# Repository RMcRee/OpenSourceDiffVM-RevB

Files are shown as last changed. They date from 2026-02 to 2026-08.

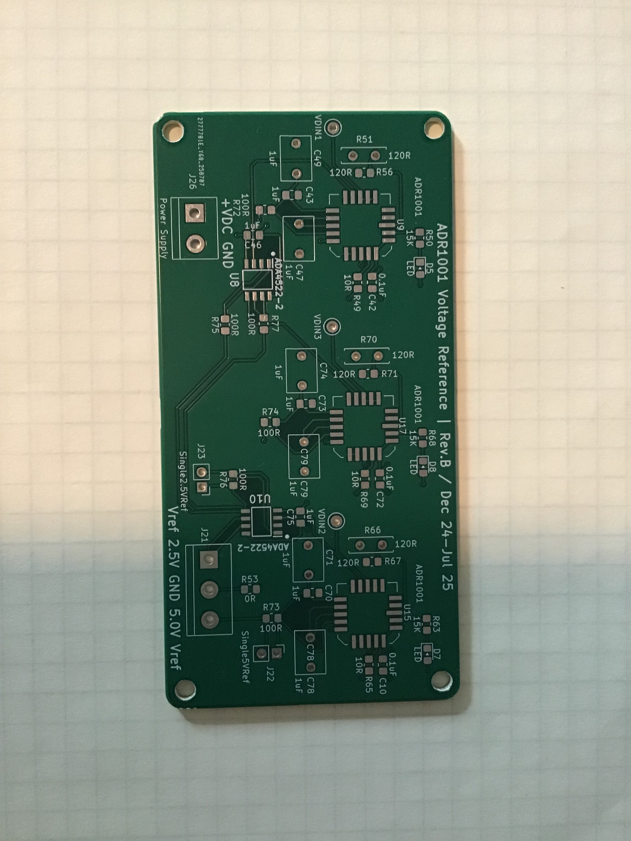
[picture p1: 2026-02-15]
ADR1001-board.jpg

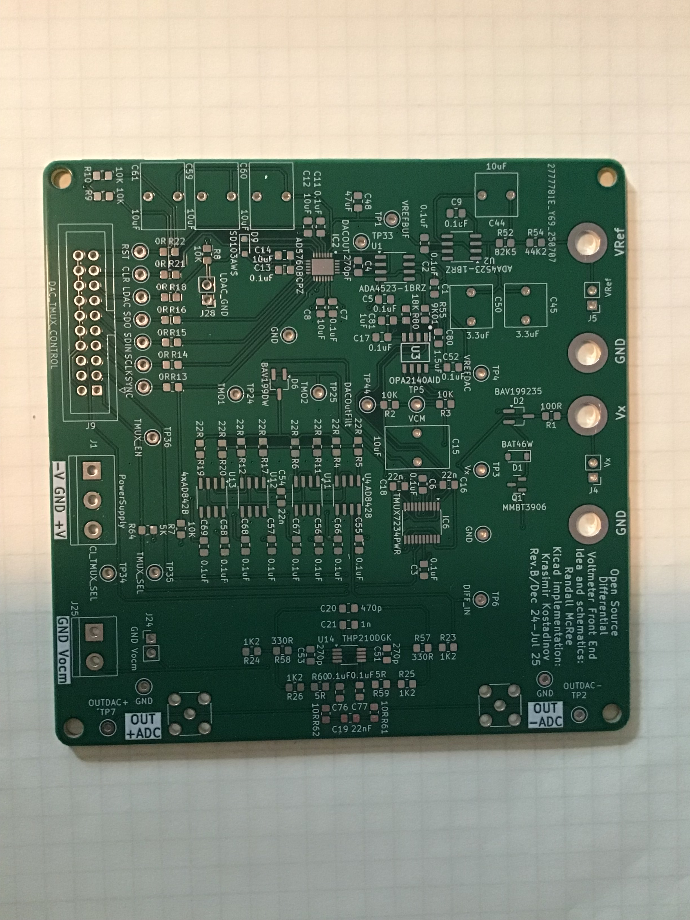
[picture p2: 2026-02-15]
Analog-front-end-board.jpg

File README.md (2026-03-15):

# Who is responsible
```
Schematic by Randall McRee 
PCB layout by Krasimir Kostadinov 
Software mostly from Claude 
```

# OpenSourceDiffVM-RevB

A high-resolution differential voltmeter (8.5-9.5 digit) with nanovolt-level sensitivity, based on the Analog Devices article on [low-noise instrumentation amplifiers](https://www.analog.com/en/resources/analog-dialogue/articles/low-noise-inamp-nanovolt-sensitivity.html).

## How It Works

An unknown voltage Vx is compared against a precision 16-bit DAC using a chopped measurement topology. The DAC output tracks Vx to within a few millivolts, and a high-gain instrumentation amplifier amplifies the residual difference for digitization by a 24-bit ADC. Chopping at ~385 Hz cancels preamp offset and 1/f noise.

```
Unknown Vx ──┐
             ├──[TMUX SPDT]──► AD8428 x4 ──► ADS127L11 ──► Teensy 4.x
DAC Output ──┘   (chopped)    (×2000 gain)   (24-bit ADC)
```

**Measurement equation:** `Vx = DAC_voltage + (ADC_mean / preamp_gain) × divider_ratio`

The DAC is calibrated against three ADR1001 ultra-stable voltage references (0.05 ppm/C) with 1000+ hour burn-in. Real-time drift compensation tracks the reference filter lag.

## Key Components

| Component | Function |
|---|---|
| 4x AD8428 | Ultra-low-noise instrumentation amplifier (1.5 nV/rtHz), gain = 2000 |
| TMUX7234 | Low-charge-injection SPDT switches for input chopping |
| ADS127L11 | 24-bit delta-sigma ADC, ~3906 SPS |
| AD5760 | 16-bit precision DAC, tracks unknown input |
| 3x ADR1001 | Ultra-stable voltage references, filtered and averaged |
| Teensy 4.1 | ARM Cortex-M7 @ 600 MHz, hardware 64-bit double |

## Voltage Ranges

| Range | Method | Resolution |
|---|---|---|
| +/-5V | Direct input | ~0.15 nV/count |
| +/-50V | Caddock 1776-C4815 divider (1:10, hardwired) | ~1.5 nV |
| +/-500V | Parallel tap (1:108.76) | ~16 nV |
| +/-5kV | Parallel tap (1:984.65) | ~150 nV |

## Firmware

The firmware runs on Teensy 4.1 and provides:

- **Serial command interface** over USB (115200 baud) — type `help` for commands
- **Channel scanning** — configure a scan list of up to 7 input channels
- **Three output modes** — human-readable, CSV for logging, Arduino Serial Plotter
- **Configurable integration** — 10 to 10,000 chop cycles per reading
- **Auto-zero** — periodic GND measurement for offset tracking
- **Reference drift compensation** — real-time prediction of filter lag error
- **DAC auto-adjustment** — binary search to keep preamp in range
- **Power-on self-test** — 9 hardware verification tests
- **EEPROM persistence** — save/load configuration across power cycles

### Building

Requires [Teensy board support](https://www.pjrc.com/teensy/td_download.html) for Arduino.

```bash
# Arduino CLI
arduino-cli compile --fqbn teensy:avr:teensy41 OpenSourceDiffVM-RevB.ino
arduino-cli upload --fqbn teensy:avr:teensy41 -p COM_PORT OpenSourceDiffVM-RevB.ino
```

### Serial Commands

Connect at 115200 baud. Key commands:

```
scan add Vx          # Add channel to scan list
scan add VrefRaw     # Add another channel
scan start           # Begin scanning
scan stop            # Stop scanning
log start            # Switch to CSV output
plot start           # Switch to Serial Plotter output
integrate 200        # Set 200 chop cycles per reading
autozero on          # Enable periodic zero calibration
range 100            # Set HV divider to +/-500V
zero                 # Immediate zero calibration
status               # Show current configuration
config save          # Persist to EEPROM
help                 # List all commands
```

### CSV Output Format

```
# timestamp_ms,channel,voltage_V,uncertainty_V,stddev_counts,mean_counts,n,dac_code,drift_ppb
123456,Vx,1.234567890123e-03,1.230000000000e-09,8.234,12345.678,100,12345,5.060
```

## PC Companion Script

`tools/diffvm.py` provides host-side functionality:

```bash
pip install pyserial matplotlib pyyaml

# Interactive terminal
python tools/diffvm.py --port COM3

# Configure from file and start scanning
python tools/diffvm.py --port COM3 --config tools/diffvm_config.yaml

# Log CSV to disk
python tools/diffvm.py --port COM3 --config tools/diffvm_config.yaml --log ./logs

# Live matplotlib plot
python tools/diffvm.py --port COM3 --config tools/diffvm_config.yaml --plot

# Full operation: config + log + plot
python tools/diffvm.py --port COM3 --config tools/diffvm_config.yaml --log ./logs --plot
```

See `tools/diffvm_config.yaml` for configuration options.

## Hardware Design

KiCad 8 project files are in `DiffVM/`:

| File | Description |
|---|---|
| `DiffVM_4L.kicad_sch` | Root schematic (4-layer PCB) |
| `FrontEnd.kicad_sch` | TMUX switches, AD8428 preamp chain, AD5760 DAC |
| `DAC.kicad_sch` | ADS127L11 ADC and Teensy interface |
| `VRef.kicad_sch` | 3x ADR1001 voltage references |
| `DiffVM_4L.kicad_pcb` | PCB layout |

## Design Notes

| Document | Description |
|---|---|
| [`filter-design.md`](filter-design.md) | Workflow for building precision low-pass filters with measured capacitors and calculated resistors |
| [`Calibration.md`](Calibration.md) | Calibration procedures and constants |
| [`ADC_analysis.md`](ADC_analysis.md) | ADS127L11 configuration, filter selection, and ENOB analysis |

## References

- [Low-Noise Instrumentation Amplifier with Nanovolt Sensitivity](https://www.analog.com/en/resources/analog-dialogue/articles/low-noise-inamp-nanovolt-sensitivity.html) (Analog Devices)
- [AD8428 datasheet](https://www.analog.com/media/en/technical-documentation/data-sheets/AD8428.PDF)
- [ADS127L11 datasheet](https://www.ti.com/lit/ds/symlink/ads127l11.pdf)
- [AD5760 datasheet](https://www.analog.com/media/en/technical-documentation/data-sheets/AD5760.pdf)

## License

Licensed under the [CERN Open Hardware Licence Version 2 - Permissive](LICENSE) (CERN-OHL-P v2).

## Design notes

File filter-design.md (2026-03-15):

# Precision Low-Pass Filter Design Workflow

This workflow produces filters whose actual characteristics (step response, −3 dB frequency, Q)
match the design intent, by calibrating resistor values to the measured capacitance of the
specific capacitors installed. 0.1% resistors compensate for 5% capacitor tolerance, so the
result is bang on rather than left to chance.

---

## Step 1 — Choose the Filter Type and Target Specification

Use a filter calculator to select topology (Butterworth, Chebyshev, Bessel, Sallen-Key, etc.),
order, −3 dB frequency, and Q. Good calculators:

- Okawa Electric (Sallen-Key and multi-feedback): http://sim.okawa-denshi.jp/en/OPseikiLowkeisan.htm
- Analog Devices Filter Wizard (full active filter synthesis): https://tools.analog.com/en/filterwizard/

Work through the trade-offs here — filter order, noise bandwidth, and the −3 dB point interact.
Higher order gives sharper roll-off but more poles to compensate. Use the calculator to make
these constraints visible before committing to a topology.

---

## Step 2 — Choose the Capacitors First

Good capacitor dielectric matters more than resistance precision at this stage.

**Dielectric preference (best to acceptable):**
1. Polypropylene film (e.g. Panasonic ECW series) — very low loss, excellent stability
2. Polyester film (MKS2 / MKP) — good for less critical nodes
3. C0G/NP0 ceramic — acceptable for small values only

Film capacitors are physically large. As part of the design, use the smallest capacitance values
that still meet the frequency and noise requirements. This is another trade-off to resolve at
the calculator stage: smaller C → larger R → more thermal noise from the resistors.

**Target part:** Panasonic ECW series polypropylene is a good default choice.

**Practical tip:** It is very useful to keep an assortment of film capacitors and 0.1% resistors
on hand for experimentation. Having a range of values available makes it easy to iterate at the
bench — measure a few candidates, pick the best pair, and calculate resistors on the spot without
waiting for parts to arrive.

**Recommended resistor kit:** Susumu RR1220PD-KIT-FILE — 0402 0.1% thin-film resistors covering
the full E96 range, 25 ppm/°C temperature coefficient. The low TC is important for precision
filters: a resistor that drifts with temperature shifts the −3 dB frequency and Q, degrading
the carefully calculated characteristic. Ideal for synthesizing precise values by series/parallel
combination.

---

## Step 3 — Measure the Actual Capacitor Values

Take a batch of capacitors of the desired nominal value and measure each one with an LCR meter.
Select one or two for the circuit. Record their **exact measured values** — these go into the
calculator in the next step, not the nominal values.

This is the key step that separates a precision filter from a typical one. A 5% capacitor
labeled 100 nF might measure anywhere from 95 nF to 105 nF; using the actual value ensures
the resistors will be calculated to compensate.

---

## Step 4 — Back-Calculate the Resistor Values

Return to the Okawa calculator (or equivalent). On the component-value sheet:

- Enter the **measured** capacitor values (from Step 3)
- Enter the **target Q** and **target −3 dB frequency** (from Step 1)
- Let the calculator solve for the required resistor values

The resulting R values will be non-standard — this is expected and correct.

---

## Step 5 — Synthesize the Resistor Values

Match the calculated R values using 0.1% tolerance resistors. Three approaches:

1. **Direct match** — if a standard 0.1% E96 value is within tolerance of the target, use it.
2. **Series combination** — R_total = R1 + R2 (easy, additive, no interaction)
3. **Parallel combination** — R_total = (R1 × R2) / (R1 + R2) (useful for fine trimming)

Target accuracy: get within ~0.1% of the calculated value. This keeps the filter characteristic
error well below what capacitor measurement uncertainty introduces.

---

## Step 5.5 — Verify "Close Enough" Before Synthesizing

Before going to the trouble of combining resistors, check whether the nearest standard 0.1%
values are already acceptable. Plug all values — measured capacitances and the candidate
standard resistors — back into the Okawa calculator and inspect the resulting Q, −3 dB
frequency, and step response.

If the deviation from the target is acceptable for your application, use those resistors as-is
and skip to Step 6. If not, proceed with Step 5's series/parallel synthesis to hit the
calculated values more precisely.

---

## Step 6 — Assemble and Verify

Build the circuit with the selected capacitors and synthesized resistors. Verify:

- **Step response** — rise time, settling behavior, overshoot should match simulation
- **−3 dB frequency** — measure with a signal generator and scope or network analyzer
- **Passband ripple / Q** — confirm the response shape matches the target topology

With measured capacitors and calculated resistors, the circuit should be correct on the first
build.

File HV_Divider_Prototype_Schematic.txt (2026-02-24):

================================================================================
        HV DIVIDER PROTOTYPE SCHEMATIC - ST-1 STRIPBOARD LAYOUT
================================================================================
Rev: B (MUX36D04 replaces ADG1411, OPA828 buffer added)
Date: 2026-01-27
Board: Busboard ST-1 (4" x 3.25")
Teensy 4.1 footprint: 3" x 1.5" in lower-left corner

================================================================================
                          SYSTEM BLOCK DIAGRAM
================================================================================

    HV INPUT (up to ±5000V)
         |
    [F1: 0ADAC0200-BE Fuse, 200mA/1kV]
         |
         v
    +-----------------------------+
    |  4x CADDOCK 1776-C4815      |
    |  Serial-Parallel Divider    |
    |  Pair AB (A||B) in series   |
    |  with Pair CD (C||D)        |
    +--------+--------------------+
             |
     AB3,AB4,AB5   CD3,CD4,CD5       Tap points
        |    |    |    |    |    |
        v    v    v    v    v    v
    +-----------------------------+
    |  MUX36D04 (U1)             |
    |  Dual 4:1 low-leakage mux  |
    |  MUX_A: selects AB tap     |----→ Teensy Pin 26 (A0)
    |  MUX_B: selects CD tap     |----→ Teensy Pin 27 (A1)
    |  DA tied to DB             |      EN hardwired to VDD (active high)
    +--------+--------------------+
             |
             | (Selected taps bridged via DA-DB)
             |
             v (CD2 = divider output)
    +-----------------------------+
    |  OPA828 (U2)               |
    |  Unity-gain voltage follower|
    |  High-Z input, low-Z output|
    +--------+--------------------+
             |
             v
    +-----------------------------+
    |  TPD4E1B06 (U3)            |
    |  ESD Protection (<50pA)    |
    +--------+--------------------+
             |
             v
    +-----------------------------+
    |  MUX36D08 (U4)             |
    |  Input S6 (HVDivider)      |----→ Teensy Pins 5,6,7 (A0,A1,A2)
    |                             |      EN hardwired to VDD (active high)
    +--------+--------------------+
             |
             v
        To Preamp (AD8428 chain)

================================================================================
              CADDOCK 1776-C4815 SERIAL-PARALLEL ARRANGEMENT
================================================================================

The Caddock 1776-C4815 is a 7-terminal precision decade divider.

PHYSICAL ARRANGEMENT (4 dividers: A, B, C, D):
  - Pair AB: Dividers A and B wired in parallel (all pins tied together)
  - Pair CD: Dividers C and D wired in parallel (all pins tied together)
  - Series: AB feeds into CD

Pin connections within pairs:
  A1-B1, A2-B2, A3-B3, A4-B4, A5-B5, A6-B6, A7-B7  -->  AB1 to AB7
  C1-D1, C2-D2, C3-D3, C4-D4, C5-D5, C6-D6, C7-D7  -->  CD1 to CD7

SERIES TOPOLOGY:

     HV INPUT ──[FUSE]──┐
                        │
                       AB1 (Pair AB input)
                        │
                        R
                        │
                       AB2 ─────────────────────────────── CD1 (Pair CD input)
                        │                                   │
                        R                                   R
                        │                                   │
                       AB3 ─── MUX36D04 S1A ──┐            CD3 ─── MUX36D04 S1B
                        │                     │             │
                        R                  DA─┴─DB          R
                        │                (tied together)    │
                       AB4 ─── MUX36D04 S2A ──┘            CD4 ─── MUX36D04 S2B
                        │         (only one              │
                        R          pair active            R
                        │          at a time)             │
                       AB5 ─── MUX36D04 S3A               CD5 ─── MUX36D04 S3B
                        │                                   │
                        R                                   R
                        │                                   │
                       AB6     (unused)                    CD6 (unused)
                        │                                   │
                        R                                   R
                        │                                   │
                       AB7 ◄──────────────────────────────  CD2 ──► OPA828 ──► TPD4E1B06 ──► MUX S6
                                (feedback)                  │
                                                            R
                                                            │
                                                           CD7 ──► GND

DIVIDER RATIOS (MUX36D04 address selection):

  Address 0 (A1=0, A0=0): S1A-DA-DB-S1B bridges AB3 to CD3 → ÷10   (±50V)
  Address 1 (A1=0, A0=1): S2A-DA-DB-S2B bridges AB4 to CD4 → ÷100  (±500V)
  Address 2 (A1=1, A0=0): S3A-DA-DB-S3B bridges AB5 to CD5 → ÷1000 (±5000V)
  Address 3 (A1=1, A0=1): S4A/S4B spare (NC sources)       → off

Note: Exact ratios depend on Caddock internal resistor values.
      Calibration required for precision measurements.

================================================================================
                     MUX36D04 DUAL 4:1 MUX (U1)
================================================================================

Low-leakage dual 4:1 analog multiplexer (<1pA at 25°C).
Each half selects one of four sources to its drain output.
EN is active HIGH.

MUX36D04 Pinout (TSSOP-16):
                    ┌────────────────┐
        A0  1  ─────┤                ├───── 16  A1
        EN  2  ─────┤                ├───── 15  GND
       VSS  3  ─────┤                ├───── 14  VDD
       S1A  4  ─────┤   MUX36D04    ├───── 13  S1B
       S2A  5  ─────┤   (TSSOP-16)  ├───── 12  S2B
       S3A  6  ─────┤                ├───── 11  S3B
       S4A  7  ─────┤                ├───── 10  S4B
        DA  8  ─────┤                ├───── 9   DB
                    └────────────────┘

Signal Connections:
  MUX_A sources (AB divider taps):
    Pin 4  (S1A) ────────────► AB3 (÷10 tap)
    Pin 5  (S2A) ────────────► AB4 (÷100 tap)
    Pin 6  (S3A) ────────────► AB5 (÷1000 tap)
    Pin 7  (S4A) ────────────► NC (spare)

  MUX_B sources (CD divider taps):
    Pin 13 (S1B) ────────────► CD3 (÷10 tap)
    Pin 12 (S2B) ────────────► CD4 (÷100 tap)
    Pin 11 (S3B) ────────────► CD5 (÷1000 tap)
    Pin 10 (S4B) ────────────► NC (spare)

  Drains (tied together to bridge selected taps):
    Pin 8  (DA) ─────────────┬──────► Pin 9 (DB)
                             │
                        (bridge wire)

Control Connections:
  Pin 1  (A0) ──────────────► Teensy Pin 26 (DIVMUX_A0)
  Pin 16 (A1) ──────────────► Teensy Pin 27 (DIVMUX_A1)
  Pin 2  (EN) ──────────────► VDD (+15V, hardwired ON, active high)

Power Connections:
  Pin 14 (VDD) ─────────────► +15V
  Pin 3  (VSS) ─────────────► -15V
  Pin 15 (GND) ─────────────► Ground
  0.1 µF cap: VDD (pin 14) to GND (pin 15)
  0.1 µF cap: GND (pin 15) to VSS (pin 3)

================================================================================
                    OPA828 VOLTAGE FOLLOWER (U2)
================================================================================

Wideband unity-gain buffer isolates divider output impedance
from MUX36D08 and downstream signal chain.

OPA828 Pinout (SOIC-8):
                    ┌──────────────┐
        NC  1  ─────┤              ├───── 8  NC
       IN-  2  ─────┤              ├───── 7  +VS
       IN+  3  ─────┤   OPA828    ├───── 6  OUT
       -VS  4  ─────┤              ├───── 5  NC
                    └──────────────┘

Signal Connections (unity-gain follower):
  Pin 3  (IN+) ─────────────► CD2 (divider output node)
  Pin 2  (IN-) ─────────────► Pin 6 (OUT) (feedback for unity gain)
  Pin 6  (OUT) ─────────────► TPD4E1B06 Pin 1 (IO1)

Power Connections:
  Pin 7  (+VS) ─────────────► +15V
  Pin 4  (-VS) ─────────────► -15V
  0.1 µF cap: +VS (pin 7) to GND
  0.1 µF cap: GND to -VS (pin 4)
  10 µF tantalum: +VS to GND (bulk decoupling)

Unused: Pins 1, 5, 8 → NC

================================================================================
                    TPD4E1B06 ESD PROTECTION (U3)
================================================================================

4-channel ultra-low leakage ESD protection device.
Leakage: <50pA at 5V (critical for nanovolt measurements)

TPD4E1B06 Pinout (SOT-363):
                    ┌────────────────┐
         IO1   1 ───┤                ├─── 6   VCC
         IO2   2 ───┤   TPD4E1B06   ├─── 5   IO4
         GND   3 ───┤                ├─── 4   IO3
                    └────────────────┘

Connections:
  Pin 1 (IO1) ────────────► OPA828 output (pin 6)
                            AND continues to MUX36D08 S6 input
  Pin 3 (GND) ────────────► Ground
  Pin 6 (VCC) ────────────► +5V
  0.1 µF cap: VCC (pin 6) to GND (pin 3)

  Pins 2, 4, 5 → NC

================================================================================
                         FUSE (F1: 0ADAC0200-BE)
================================================================================

Eaton/Bussmann high-voltage DC fuse.
Rating: 200mA, 1000VDC

Fuse Placement:
  HV Input Jack ──────[F1]────────► AB1 (Caddock pair AB input)

Mount fuse in holder external to stripboard with adequate voltage clearance.

================================================================================
                    MUX36D08 (U4, existing in system)
================================================================================

8:1 low-leakage analog multiplexer. EN is active HIGH.

Connections for HV divider:
  S6 input ◄──────────────── TPD4E1B06 IO1 / OPA828 output

Control (to Teensy):
  A0 ────────────────────────► Teensy Pin 5
  A1 ────────────────────────► Teensy Pin 6
  A2 ────────────────────────► Teensy Pin 7
  EN ────────────────────────► VDD (hardwired ON, active high)

MUX Address for S6 (HVDivider): A2=1, A1=0, A0=1 (address = 5)
Corresponds to InputChannel::HVDivider in firmware.

================================================================================
                      COMPLETE SCHEMATIC DIAGRAM
================================================================================

                              +15V           -15V           +5V
                               │              │              │
    ┌──────────────────────────┼──────────────┼──────────────┼──────────────────┐
    │                          │              │              │                  │
HV+ ──[F1: 200mA/1kV]─────────────────────────────────────────────────────────►AB1
    │                          │              │              │                  │
    │  ╔═══════════════════════│══════════════│══════════════│════════════════╗ │
    │  ║     CADDOCK PAIR AB   │              │              │               ║ │
    │  ║                       │              │              │               ║ │
    │  ║  AB1──R──AB2──R──AB3──R──AB4──R──AB5──R──AB6──R──AB7               ║ │
    │  ║               │    │       │       │              ▲                 ║ │
    │  ╚═══════════════│════│═══════│═══════│══════════════│═════════════════╝ │
    │                  │    │       │       │              │                   │
    │                  │  ┌─┴───────┴───────┴─┐           │                   │
    │                  │  │ MUX36D04 (U1)     │           │                   │
    │                  │  │ MUX_A:            │           │                   │
    │                  │  │  S1A=AB3 (÷10)    │           │                   │
    │                  │  │  S2A=AB4 (÷100)   │           │                   │
    │                  │  │  S3A=AB5 (÷1000)  │           │                   │
    │                  │  │  S4A=NC           │           │                   │
    │                  │  │                   │           │                   │
    │                  │  │  DA ──── DB       │           │                   │
    │                  │  │  (tied together)  │           │                   │
    │                  │  │                   │           │                   │
    │                  │  │ MUX_B:            │           │                   │
    │                  │  │  S1B=CD3 (÷10)    │           │                   │
    │                  │  │  S2B=CD4 (÷100)   │           │                   │
    │                  │  │  S3B=CD5 (÷1000)  │           │                   │
    │                  │  │  S4B=NC           │           │                   │
    │                  │  └─┬───────┬───────┬─┘           │                   │
    │                  │    │       │       │              │                   │
    │  ╔═══════════════│════│═══════│═══════│══════════════│═════════════════╗ │
    │  ║     CADDOCK   │    │       │       │              │     PAIR CD     ║ │
    │  ║               │    │       │       │              │                 ║ │
    │  ║  CD1──R──CD2──R──CD3──R──CD4──R──CD5──R──CD6──R──CD7               ║ │
    │  ║   ▲      │                                        │                ║ │
    │  ╚═══│══════│════════════════════════════════════════│════════════════╝ │
    │      │      │                                        │                  │
    │      │      │                                        ▼                  │
    │ (AB2→CD1)   │                                      GND                  │
    │             │                                                           │
    │             ▼                                                           │
    │      ┌──────────────┐                                                   │
    │      │  OPA828 (U2) │  Unity-gain voltage follower                      │
    │      │  IN+ ← CD2   │  Powered: ±15V                                   │
    │      │  IN- → OUT   │                                                   │
    │      └──────┬───────┘                                                   │
    │             │                                                           │
    │             ▼                                                           │
    │      ┌──────────────┐                                                   │
    │      │ TPD4E1B06    │  ESD Protection                                   │
    │      │  (U3)        │  Powered: +5V                                     │
    │      └──────┬───────┘                                                   │
    │             │                                                           │
    │             ▼                                                           │
    │      ┌──────────────┐                                                   │
    │      │ MUX36D08     │  Input Channel Select                             │
    │      │  (U4) S6     │  EN hardwired to VDD (active high)                │
    │      └──────┬───────┘                                                   │
    │             │                                                           │
    │             ▼                                                           │
    │        To Preamp (AD8428 chain)                                         │
    │                                                                         │
HV- ──────────────────────────────────────────────────────────────────────► GND
    │
   ═╧═ Chassis Ground (safety)

    Control Lines (5 total, all to Teensy):
    ────────────────────────────────────────
    Teensy Pin 26 ─────────► U1 MUX36D04 A0 (pin 1)
    Teensy Pin 27 ─────────► U1 MUX36D04 A1 (pin 16)
    Teensy Pin 5  ─────────► U4 MUX36D08 A0
    Teensy Pin 6  ─────────► U4 MUX36D08 A1
    Teensy Pin 7  ─────────► U4 MUX36D08 A2

    Hardwired (no GPIO):
    U1 MUX36D04 EN (pin 2)  → VDD (+15V, active high)
    U4 MUX36D08 EN           → VDD (active high)

================================================================================
                         TEENSY PIN ALLOCATION
================================================================================

Existing Pins (from firmware):
  Pin 2   - TMUXSEL
  Pin 3   - CI_TMUXSEL
  Pin 4   - TMUX_EN
  Pin 5   - INMUX_A0 (MUX36D08)
  Pin 6   - INMUX_A1 (MUX36D08)
  Pin 7   - INMUX_A2 (MUX36D08)
  Pin 8   - FREE (was INMUX_EN, now hardwired)
  Pin 9   - ADC Clock (PWM)
  Pin 10  - DAC CS
  Pin 11  - SPI MOSI
  Pin 12  - SPI MISO
  Pin 13  - SPI SCK
  Pin 15  - ADC DRDY
  Pin 24  - DAC Clear
  Pin 25  - DAC Reset
  Pin 41  - ADC CS

NEW Pins for MUX36D04:
  Pin 26  - DIVMUX_A0 (MUX36D04 A0, pin 1)
  Pin 27  - DIVMUX_A1 (MUX36D04 A1, pin 16)

================================================================================
                         POWER SUPPLY REQUIREMENTS
================================================================================

MUX36D04 (U1):
  VDD: +15V (pin 14)
  VSS: -15V (pin 3)
  EN:  +15V (pin 2, hardwired active high)
  GND: 0V   (pin 15)

OPA828 (U2):
  +VS: +15V (pin 7)
  -VS: -15V (pin 4)

TPD4E1B06 (U3):
  VCC: +5V  (pin 6)
  GND: 0V   (pin 3)

MUX36D08 (U4):
  EN:  VDD  (hardwired active high)
  (remaining power from existing system)

Bypass capacitors:
  0.1 µF: U1 VDD-GND, U1 GND-VSS
  0.1 µF: U2 +VS-GND, U2 GND-(-VS)
  10 µF:  U2 +VS-GND (bulk)
  0.1 µF: U3 VCC-GND

================================================================================
                              END OF SCHEMATIC
================================================================================

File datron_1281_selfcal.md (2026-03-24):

# Datron/Wavetek/Fluke 1281 — Selfcal Dual-Reference Architecture

## Instrument Overview

The **Datron 1281** (later sold as Wavetek 1281, then Fluke 1281) is an 8.5-digit metrology-grade
DC voltmeter, broadly comparable to the HP/Agilent 3458A and Fluke 8508A. It is notable for its
"Selfcal" self-calibration system, which allows reference drift to be detected and corrected without
an external standard between annual calibrations.

| Specification | Value |
|---|---|
| Resolution | 8.5 digits |
| DC voltage stability | 3 ppm / year (±5 °C) |
| 10 V range linearity | ±0.1 ppm |
| DC input amp TC | 0.25 µV/°C |

---

## Reference Hardware

The 1281 uses **two independent LTZ1000-based reference modules** (Datron part 400763-1), each
containing:
- Linear LTZ1000 subsurface Zener diode with integrated heater and temperature sensor
- Hermetically sealed Vishay metal-foil resistor networks
- Constant-temperature oven control (on-chip)

The two modules are kept **electrically separate** — they are NOT averaged together. This
independence is the foundation of the Selfcal technique.

---

## Selfcal Architecture

### Core Idea

Any single reference can drift without being detectable. Two independent references allow drift to
be seen as a change in their *ratio*. If the ratio is anchored to a known-good external calibration,
deviations from that anchor are measurable corrections.

### Phase 1: External Calibration (annual)

1. Instrument is calibrated against a traceable standard (e.g., Josephson voltage standard,
   calibrated Fluke 732, or national laboratory transfer standard).
2. Both reference modules are measured under identical conditions.
3. The ratio `R_char = Ref_A / Ref_B` is stored in NV memory as the **Selfcal characterization
   factor**, alongside the normal absolute calibration constants.
4. This ratio is now a traceable anchor — it encodes the relationship between the two references
   at the moment of known-good calibration.

### Phase 2: Self-Calibration (user-initiated, no external standard needed)

1. The instrument measures both reference modules using the same internal measurement chain.
2. Current ratio: `R_now = Ref_A / Ref_B`
3. Delta: `delta_R = R_now - R_char`
4. A third set of calibration constants ("Selfcal corrections") is computed from `delta_R` and
   applied multiplicatively to all subsequent readings.
5. The correction tracks absolute drift because `R_char` was established at external-cal time.

```
Vx_corrected = Vx_measured × (1 + delta_R / R_char)
```

### Limitation

If both references drift at **exactly the same rate** (perfectly correlated), the ratio is
unchanged and drift is invisible. In practice, same-batch LTZ1000 units have similar but not
identical aging curves, so this failure mode is rare. The technique is not a substitute for
periodic external calibration — it extends the validity of the last external cal between annual
intervals.

---

## Why This Is Relevant to the DiffVM

### Current DiffVM Architecture

The DiffVM averages three ADR1001 references in the **analog domain** before the firmware sees
them. The firmware can measure `VrefRaw` (pre-filter average at J3 via MUX channel S3), but
cannot distinguish the contribution of individual references. This means:

- A single ADR1001 that has drifted or failed is invisible to the firmware
- The drift compensation system (filter-lag prediction) operates on the aggregate average

### What a 1281-Inspired Enhancement Would Require

**Hardware change (future revision):** Route 2 of the 3 ADR1001 references to separate MUX inputs
instead of combining all three in the analog network. The firmware could then:
- Periodically measure each subgroup independently
- Compute the inter-reference ratio
- Detect and correct drift in one reference relative to the other

**Software-only analog (no hardware change):** Store a characterized `VrefRaw / nominal` ratio in
flash at external-calibration time (separate from the DAC calibration table). Track long-term
deviation from this ratio as an absolute drift anchor. This is distinct from the current short-term
filter-lag compensation — it would catch slow secular drift over days to months.

### Error Budget Impact

At 1 ppm/year ADR1001 drift (typical after burn-in), the current design with three averaged
references has a correlated drift floor. A dual-reference inter-comparison could detect uncorrelated
drift at the ~0.3 ppm level (one reference drifting against the other two), improving the
long-term absolute accuracy floor.

---

## External References

| Resource | URL |
|---|---|
| xDevs.com — detailed teardown, repair, calibration worklog | https://xdevs.com/fix/d1281/ |
| Datron 1281 datasheet | https://www.testequipmenthq.com/datasheets/DATRON-1281-Datasheet.pdf |
| Wavetek 1281 datasheet | https://www.testequipmenthq.com/datasheets/WAVETEK-1281-Datasheet.pdf |
| LTZ1000 product page (Analog Devices) | https://www.analog.com/en/products/ltz1000.html |
| LTZ1000 Wikipedia | https://en.wikipedia.org/wiki/LTZ1000 |

The **xDevs worklog** is the most technically detailed public resource — it includes high-resolution
PCB photos, circuit tracing, component identification, and a detailed account of the Selfcal
calibration procedure. Recommended as the primary reference.

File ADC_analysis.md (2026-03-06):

# ADS127L11 Configuration Analysis

Generated by reviewing the ADS127L11 datasheet against firmware `OpenSourceDiffVM-RevB.ino`.

---

## Register Configuration

| Register | Value | Set by firmware |
|---|---|---|
| CONFIG1 | 0x00 (reset default) | No — left at default after RESET |
| CONFIG2 | 0x00 (reset default) | No — left at default after RESET |
| CONFIG3 | 0x18 = 0b00011000 | Yes — `initAdc()` |
| CONFIG4 | 0x80 = 0b10000000 | Yes — `initAdc()` |

**CONFIG3 breakdown:**
- `DELAY[2:0]` = 000 → 0 fMOD cycles conversion-start delay
- `FILTER[4:0]` = 11000b → **Sinc4 (OSR = 32) + Sinc1 (OSR = 100)**

**CONFIG4 breakdown:**
- Bit 7 `CLK_SEL` = 1 → **External clock** (25 MHz from Teensy)
- All other bits = 0 (defaults)

**CONFIG1 / CONFIG2 defaults (not explicitly written):**
- CONFIG1 = 0: 1× input range, no input precharge buffers, no VCM output, low reference range
- CONFIG2 = 0: High-speed mode (`SPEED_MODE` = 0, requires fMOD ≥ 12.5 MHz), data-output mode

> **Fragility note:** CONFIG1 and CONFIG2 are never explicitly written. Any spurious RESET would
> leave CONFIG4 at 0x00, switching to the internal oscillator. These registers should be written
> explicitly during `initAdc()` as a defensive measure.

---

## Filter Selection: Sinc4 + Sinc1, OSR = 3200

From Table 8-25 (CONFIG3 FILTER[4:0] field descriptions):

```
FILTER = 11000b (24) = Sinc4 (OSR = 32) + Sinc1 (OSR = 100)
Total decimation ratio = 32 × 100 = 3200
```

Signal path through the digital filter:
```
Modulator (fMOD = 12.5 MHz)
    → Sinc4 decimator (OSR = 32) → 390.625 kHz intermediate rate
    → Sinc1 decimator (OSR = 100) → 3906.25 SPS output
```

### Filter Characteristics at fMOD = 12.5 MHz

| Parameter | Value |
|---|---|
| Output data rate | 12.5 MHz / 3200 = **3906.25 SPS** |
| Sinc4 intermediate rate | 390.625 kHz |
| −3 dB bandwidth | ≈ 0.443 × 390.625 kHz / 100 ≈ **1730 Hz** |
| Sample period | 256 µs |
| Group delay (approx) | sinc4: 31/fMOD ≈ 2.5 µs + sinc1: 99 × 2.56 µs ≈ **256 µs total** |

The Sinc4 stage provides sharp nulls at multiples of fMOD/32 = 390.625 kHz, strongly rejecting
clock-related interference. The Sinc1 stage does the bulk averaging down to the final output rate.

The −3 dB bandwidth of ~1730 Hz is **~4.5× above the firmware chop rate (~385 Hz)**, so the
chopped measurement signal passes through without filter-induced amplitude error.

---

## Clock Frequency Assessment

**fCLK = 25 MHz → fMOD = fCLK / 2 = 12.5 MHz**

High-speed mode requires fMOD ≥ 12.5 MHz (CONFIG2 `SPEED_MODE` = 0). The firmware operates
**exactly at the minimum boundary** for high-speed mode.

### Impact

The datasheet SNR/DR specifications for high-speed mode are tabulated at fMOD = 25.6 MHz (maximum).
Running at 12.5 MHz means the modulator oversamples the input at half the maximum rate, resulting in:

- ~3 dB higher quantization noise floor vs. operating at fMOD = 25.6 MHz
- Same output data rate (OSR = 3200 decimates away the extra samples regardless)
- Same −3 dB bandwidth

### Recommendation

The Teensy 4.x can output clock frequencies well above 25 MHz. Changing to
**fCLK = 51.2 MHz → fMOD = 25.6 MHz** (the datasheet maximum) would recover
approximately **3 dB of SNR** at no cost to data rate or bandwidth. This is the most
straightforward hardware improvement available.

---

## Effective Number of Bits (ENOB)

### ADC per-sample performance

From the ADS127L11 electrical characteristics (high-speed mode):

| Configuration | Dynamic Range | ENOB |
|---|---|---|
| Wideband filter, OSR = 64 (datasheet min) | 109 dB min / 111.8 dB typ | 17.9 bits typ |
| Sinc4 + Sinc1, OSR = 3200 (our config, estimated) | ~115–117 dB typ | ~18.9–19.2 bits |

The nominal 24-bit output word has roughly **5 LSBs of noise** at the 3906 SPS output rate.
ENOB ≈ **19 bits per output sample**.

### After averaging N chop cycles

Each doubling of averages adds 0.5 bits. The firmware accumulates statistics across
`integrationCycles` chop cycles:

| Averages (N) | Wall time | ENOB | Input-referred noise (RMS) | Limiting factor |
|---|---|---|---|---|
| 1 | ~2.6 ms | ~19 bits | ~1.5 nV (ADC-dominated) | ADC noise |
| 100 | ~260 ms | ~22 bits | ~2.7 nV | AD8428 preamp |
| 1000 | ~2.6 s | ~24 bits | ~0.85 nV | AD8428 preamp |
| 10000 | ~26 s | ~24 bits | ~270 pV | AD8428 preamp |

At N ≈ 1000 cycles, the 24-bit word length ceases to be the bottleneck. Beyond this point,
resolution is limited by the **AD8428 input noise (1.5 nV/√Hz)**, which is the intended design.
The ADC is not the limiting factor — this is correct for a nanovolt-level instrument.

### Noise budget (1-second integration, ~390 chop cycles)

| Source | Contribution (input-referred RMS) |
|---|---|
| AD8428 × 4 preamp chain | ~1.5 nV/√Hz × √(~400 Hz BW) ≈ **30 nV** per single half-cycle |
| After √390 averaging | ≈ **1.5 nV RMS** |
| ADS127L11 ADC (at N=390) | < 0.1 nV (negligible vs. preamp) |
| Reference drift (compensated) | < 25 nV (uncompensated); < a few nV (with filter-error compensation) |

---

## Summary

| Item | Assessment |
|---|---|
| Filter selection (sinc4+sinc1, OSR=3200) | Correct and well-suited for chopped DC measurement |
| Output data rate (3906.25 SPS) | Correct — matches firmware constant `EST_FSPS` |
| −3 dB bandwidth (~1730 Hz) | Good — well above chop rate, no signal attenuation |
| fCLK = 25 MHz (fMOD = 12.5 MHz) | Valid but at the minimum — upgrade to 51.2 MHz for ~3 dB improvement |
| CONFIG4 CLK_SEL=1 (external clock) | Correct |
| CONFIG1/CONFIG2 not explicitly written | Works, but fragile — recommend explicit init |
| ENOB per output sample | ~19 bits at 3906 SPS |
| ENOB after ~1000-cycle averaging | ~24 bits (then preamp-noise limited, as intended) |
| System resolution at 1 s averaging | ~1.5 nV RMS input-referred — consistent with 8.5-digit meter goal |

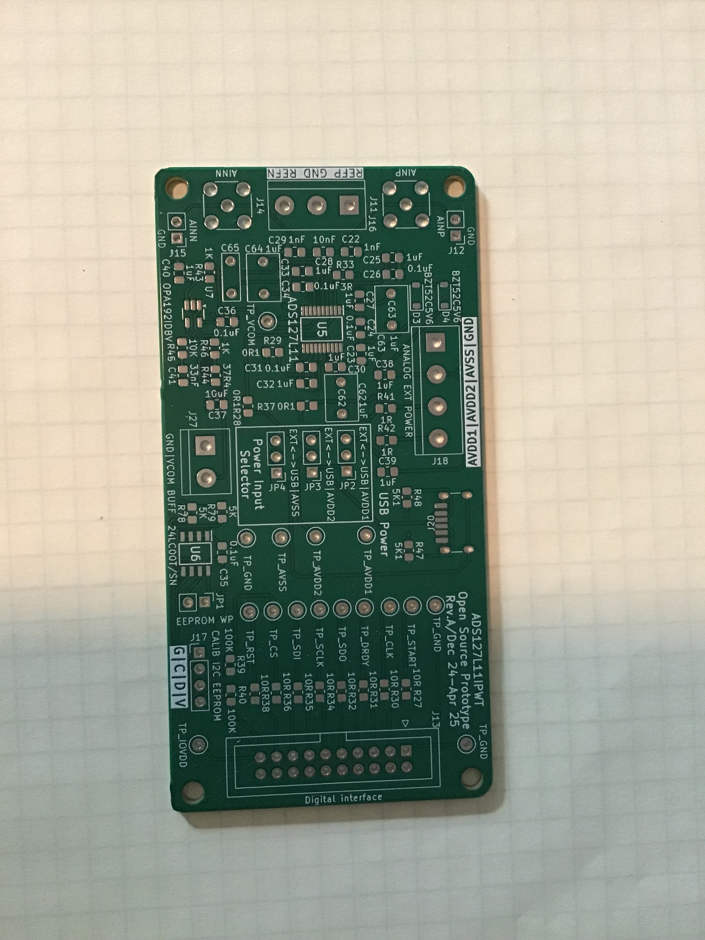
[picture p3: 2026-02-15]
ADC-board-photo.jpg

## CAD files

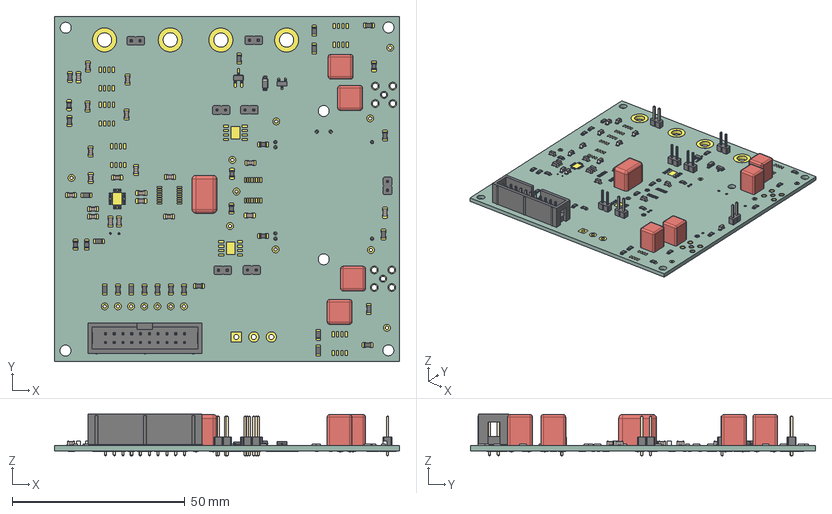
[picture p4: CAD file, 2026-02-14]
DiffVM/DiffVM_4L.step
100.0 x 100.0 x 12.1 mm
R_0805_2012Metric x 30
C_Rect_L72mm_W72mm_P500mm_FKS2_FKP2_MKS2_MKP2 x 4
C_0805_2012Metric x 21
TSOT_23
SOT_23
PinHeader_1x02_P254mm_Vertical x 7
C_Rect_L72mm_W110mm_P500mm_FKS2_FKP2_MKS2_MKP2
D_SOD_123
IDC_Header_2x10_P254mm_Vertical
_autosave-DiffVM_4L_track_1
_autosave-DiffVM_4L_track_2
_autosave-DiffVM_4L_pad_1
_autosave-DiffVM_4L_pad_2
_autosave-DiffVM_4L_pad_3
_autosave-DiffVM_4L_pad_4
_autosave-DiffVM_4L_pad_5
_autosave-DiffVM_4L_pad_6
_autosave-DiffVM_4L_pad_7
_autosave-DiffVM_4L_pad_8
_autosave-DiffVM_4L_pad_9
_autosave-DiffVM_4L_pad_10
_autosave-DiffVM_4L_pad_11
_autosave-DiffVM_4L_pad_12
_autosave-DiffVM_4L_pad_13
_autosave-DiffVM_4L_pad_14
_autosave-DiffVM_4L_pad_15
_autosave-DiffVM_4L_pad_16
_autosave-DiffVM_4L_pad_17
_autosave-DiffVM_4L_pad_18
_autosave-DiffVM_4L_pad_19
_autosave-DiffVM_4L_pad_20
_autosave-DiffVM_4L_pad_21
_autosave-DiffVM_4L_pad_22
_autosave-DiffVM_4L_pad_23
_autosave-DiffVM_4L_pad_24
_autosave-DiffVM_4L_pad_25
_autosave-DiffVM_4L_pad_26
_autosave-DiffVM_4L_pad_27
_autosave-DiffVM_4L_pad_28
_autosave-DiffVM_4L_pad_29
_autosave-DiffVM_4L_pad_30
_autosave-DiffVM_4L_pad_31
_autosave-DiffVM_4L_pad_32
_autosave-DiffVM_4L_pad_33
_autosave-DiffVM_4L_pad_34
_autosave-DiffVM_4L_pad_35
_autosave-DiffVM_4L_pad_36
_autosave-DiffVM_4L_pad_37
_autosave-DiffVM_4L_pad_38
_autosave-DiffVM_4L_pad_39
_autosave-DiffVM_4L_pad_40
_autosave-DiffVM_4L_pad_41
_autosave-DiffVM_4L_pad_42
_autosave-DiffVM_4L_pad_43
_autosave-DiffVM_4L_pad_44
_autosave-DiffVM_4L_pad_45
_autosave-DiffVM_4L_pad_46
_autosave-DiffVM_4L_pad_47
_autosave-DiffVM_4L_pad_48
_autosave-DiffVM_4L_pad_49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

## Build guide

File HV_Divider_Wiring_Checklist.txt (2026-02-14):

================================================================================
     HV DIVIDER PROTOTYPE - STRIPBOARD WIRING CHECKLIST (Rev B)
================================================================================
Rev: B (MUX36D04 replaces ADG1411, OPA828 buffer added)
Date: 2026-01-27
Board: Busboard ST-1 Stripboard (4" x 3.25", 0.1" pitch)
       ~40 columns x 32 rows (0.1" pitch)

LAYOUT CONSTRAINTS:
  - Teensy 4.1: 3" x 1.5" (30 holes x 15 holes) - LOWER LEFT corner
  - Available area: Upper portion (~17 rows) and right side (~10 columns)

================================================================================
                          COMPONENT LIST
================================================================================

Qty   Part Number         Description                        Package
----  -----------------   ---------------------------------  ---------------
4     Caddock 1776-C4815  Precision decade divider           7-pin SIP
1     MUX36D04            Dual 4:1 low-leakage analog mux   SOIC-16
1     MUX36D08            8:1 low-leakage analog mux        (existing in system)
1     OPA828              Wideband voltage follower/buffer   SOIC-8
1     TPD4E1B06DCKR       4-ch ESD protection (<50pA leak)  SOT-363
1     0ADAC0200-BE        200mA 1000V DC fuse               5x20mm cartridge
1     Fuse holder         5x20mm panel mount                Chassis mount
--    Teensy 4.1          Microcontroller (existing)        --

Breakout boards needed (for SMD parts):
1     SOIC-16 to DIP adapter (for MUX36D04)
1     SOIC-8 to DIP adapter  (for OPA828)
1     SOT-363 to DIP adapter (for TPD4E1B06)

Passive components:
3     0.1 µF ceramic      Bypass caps (MUX36D04, OPA828, TPD4E1B06)
1     10 µF tantalum      Bulk decoupling for OPA828 supply

================================================================================
                          SYSTEM BLOCK DIAGRAM
================================================================================

    HV INPUT (up to ±5000V)
         |
    [F1: 0ADAC0200-BE Fuse, 200mA/1kV]
         |
         v
    +-----------------------------+
    |  4x CADDOCK 1776-C4815      |
    |  Serial-Parallel Divider    |
    |  Pair AB (A||B) in series   |
    |  with Pair CD (C||D)        |
    +--------+--------------------+
             |
     AB3,AB4,AB5   CD3,CD4,CD5       Tap points
        |    |    |    |    |    |
        v    v    v    v    v    v
    +-----------------------------+
    |  MUX36D04 Dual 4:1 Mux     |
    |  MUX_A: selects AB tap     |----→ Teensy Pin 26 (A0)
    |  MUX_B: selects CD tap     |----→ Teensy Pin 27 (A1)
    |  DA tied to DB             |      EN hardwired ON
    +--------+--------------------+
             |
             | (Selected tap bridged)
             |
             v (CD2 = divider output)
    +-----------------------------+
    |  OPA828 Voltage Follower    |
    |  Unity gain buffer          |
    |  High-Z input, low-Z output |
    +--------+--------------------+
             |
             v
    +-----------------------------+
    |  TPD4E1B06 ESD Protection   |
    |  <50pA leakage              |
    +--------+--------------------+
             |
             v
    +-----------------------------+
    |  MUX36D08 Input S6          |----→ Teensy Pins 5,6,7 (A0,A1,A2)
    |  (channel select)           |      EN hardwired ON
    +--------+--------------------+
             |
             v
        To Preamp (AD8428 chain)

================================================================================
             TEENSY PIN ALLOCATION (5 control lines)
================================================================================

MUX36D08 (8:1 input mux):
  Teensy Pin 5  → MUX36D08 A0
  Teensy Pin 6  → MUX36D08 A1
  Teensy Pin 7  → MUX36D08 A2
  MUX36D08 EN   → Hardwired LOW (active low, always enabled)

MUX36D04 (dual 4:1 divider tap select):
  Teensy Pin 26 → MUX36D04 A0
  Teensy Pin 27 → MUX36D04 A1
  MUX36D04 EN   → Hardwired LOW (active low, always enabled)

NOTE: Teensy Pin 8 (was INMUX_EN) is now FREE - EN pins hardwired.

================================================================================
             CADDOCK DIVIDER TOPOLOGY (unchanged from Rev A)
================================================================================

     HV Input ──[FUSE]──► AB1 ──R── AB2 ──R── AB3 ──R── AB4 ──R── AB5 ──R── AB6 ──R── AB7
                                │              │         │         │                    ▲
                                │             tap       tap       tap                   │
                                │              │         │         │                    │
                       CD1 ──R── CD2 ──R── CD3 ──R── CD4 ──R── CD5 ──R── CD6 ──R── CD7
                        ▲       │        tap       tap       tap                   │
                        │       │         │         │         │                    ▼
                   (from AB2)   │        MUX36D04 bridges these                  GND
                                ▼
                          OUTPUT → OPA828 → TPD4E1B06 → MUX36D08 S6

Pair AB: Dividers A and B, all pins tied (A1-B1, A2-B2, ... A7-B7)
Pair CD: Dividers C and D, all pins tied (C1-D1, C2-D2, ... C7-D7)
Series: AB2 → CD1, CD2 → Output AND AB7 (feedback)
Ground: CD7 → GND

================================================================================
             MUX36D04 DIVIDER TAP MAPPING
================================================================================

MUX36D04 address selects which divider taps to bridge:

  Address   A1  A0   MUX_A Source   MUX_B Source   Ratio    Range
  -------   --  --   -----------    -----------    ------   --------
     0       0   0   AB3            CD3            ÷10      ±50V
     1       0   1   AB4            CD4            ÷100     ±500V
     2       1   0   AB5            CD5            ÷1000    ±5000V
     3       1   1   (spare)        (spare)        --       --

MUX_A Drain (DA) tied to MUX_B Drain (DB) → bridges selected taps.
EN hardwired LOW (always enabled) → some tap always bridged.
Use address 3 (spare, unconnected sources) as "off" state.

================================================================================
             MUX36D04 PINOUT (TSSOP-16)
================================================================================

                    ┌────────────────┐
        A0  1  ─────┤                ├───── 16  A1
        EN  2  ─────┤                ├───── 15  GND
       VSS  3  ─────┤                ├───── 14  VDD
       S1A  4  ─────┤   MUX36D04    ├───── 13  S1B
       S2A  5  ─────┤   (TSSOP-16)  ├───── 12  S2B
       S3A  6  ─────┤                ├───── 11  S3B
       S4A  7  ─────┤                ├───── 10  S4B
        DA  8  ─────┤                ├───── 9   DB
                    └────────────────┘

EN is ACTIVE HIGH: EN=HIGH → switches enabled, EN=LOW → all off.
Hardwired ON: tie EN to VDD.

================================================================================
             OPA828 PINOUT (SOIC-8, voltage follower)
================================================================================

                    ┌──────────────┐
        NC  1  ─────┤              ├───── 8  NC
       IN-  2  ─────┤              ├───── 7  +VS
       IN+  3  ─────┤   OPA828     ├───── 6  OUT
       -VS  4  ─────┤              ├───── 5  NC
                    └──────────────┘

Voltage follower wiring:
  IN+ (pin 3) = signal input (from CD2 divider output)
  IN- (pin 2) = tied to OUT (pin 6) for unity gain
  OUT (pin 6) = buffered output → TPD4E1B06 → MUX36D08 S6

NOTE: Verify this pinout against the actual OPA828 datasheet before wiring.

================================================================================
             TPD4E1B06 PINOUT (SOT-363)
================================================================================

                    ┌────────────────┐
         IO1   1 ───┤                ├─── 6   VCC
         IO2   2 ───┤   TPD4E1B06   ├─── 5   IO4
         GND   3 ───┤                ├─── 4   IO3
                    └────────────────┘

================================================================================
                    WIRING CHECKLIST
================================================================================

--- SECTION 1: CADDOCK PAIR AB (Dividers A and B in parallel) ----------------

  [ ] 1.1  Mount Caddock A (7-pin SIP)
  [ ] 1.2  Mount Caddock B (7-pin SIP) adjacent to A
  [ ] 1.3  Wire A1 to B1 → label "AB1" (HV input)
  [ ] 1.4  Wire A2 to B2 → label "AB2" (series junction)
  [ ] 1.5  Wire A3 to B3 → label "AB3" (÷10 tap)
  [ ] 1.6  Wire A4 to B4 → label "AB4" (÷100 tap)
  [ ] 1.7  Wire A5 to B5 → label "AB5" (÷1000 tap)
  [ ] 1.8  Wire A6 to B6 → label "AB6" (unused)
  [ ] 1.9  Wire A7 to B7 → label "AB7" (feedback)

--- SECTION 2: CADDOCK PAIR CD (Dividers C and D in parallel) ----------------

  [ ] 2.1  Mount Caddock C (7-pin SIP)
  [ ] 2.2  Mount Caddock D (7-pin SIP) adjacent to C
  [ ] 2.3  Wire C1 to D1 → label "CD1" (series junction)
  [ ] 2.4  Wire C2 to D2 → label "CD2" (OUTPUT)
  [ ] 2.5  Wire C3 to D3 → label "CD3" (÷10 tap)
  [ ] 2.6  Wire C4 to D4 → label "CD4" (÷100 tap)
  [ ] 2.7  Wire C5 to D5 → label "CD5" (÷1000 tap)
  [ ] 2.8  Wire C6 to D6 → label "CD6" (unused)
  [ ] 2.9  Wire C7 to D7 → label "CD7" (GND)

--- SECTION 3: SERIES CONNECTIONS (AB to CD) ---------------------------------

  [ ] 3.1  Wire AB2 → CD1 (series connection between pairs)
  [ ] 3.2  Wire CD2 → AB7 (feedback tap)
  [ ] 3.3  Wire CD7 → GND bus

--- SECTION 4: FUSE ----------------------------------------------------------

  [ ] 4.1  Mount fuse holder (external to stripboard, HV-rated wire)
  [ ] 4.2  Wire HV+ input jack → Fuse holder input
  [ ] 4.3  Wire Fuse holder output → AB1
  [ ] 4.4  Install fuse (0ADAC0200-BE, 200mA/1kV)

--- SECTION 5: MUX36D04 (Dual 4:1 Divider Tap Select) -----------------------

Mount MUX36D04 on SOIC-16 breakout board.

  Power:
  [ ] 5.1  Pin 14 (VDD) → +15V
  [ ] 5.2  Pin 3  (VSS) → -15V
  [ ] 5.3  Pin 15 (GND) → GND bus
  [ ] 5.4  Add 0.1 µF cap: VDD to GND (close to pins 14 and 15)
  [ ] 5.5  Add 0.1 µF cap: GND to VSS (close to pins 15 and 3)

  Enable (hardwired ON, active HIGH):
  [ ] 5.6  Pin 2  (EN)  → VDD (+15V) (active high = always enabled)

  Address lines (to Teensy):
  [ ] 5.7  Pin 1  (A0)  → Teensy Pin 26
  [ ] 5.8  Pin 16 (A1)  → Teensy Pin 27

  MUX_A sources (AB divider taps):
  [ ] 5.9  Pin 4  (S1A) → AB3 (÷10 tap)
  [ ] 5.10 Pin 5  (S2A) → AB4 (÷100 tap)
  [ ] 5.11 Pin 6  (S3A) → AB5 (÷1000 tap)
  [ ] 5.12 Pin 7  (S4A) → No connection (spare)

  MUX_B sources (CD divider taps):
  [ ] 5.13 Pin 13 (S1B) → CD3 (÷10 tap)
  [ ] 5.14 Pin 12 (S2B) → CD4 (÷100 tap)
  [ ] 5.15 Pin 11 (S3B) → CD5 (÷1000 tap)
  [ ] 5.16 Pin 10 (S4B) → No connection (spare)

  Drains (tied together):
  [ ] 5.17 Pin 8  (DA)  → Pin 9 (DB) (bridge wire)

--- SECTION 6: OPA828 VOLTAGE FOLLOWER ---------------------------------------

Mount OPA828 on SOIC-8 breakout board.

  Power:
  [ ] 6.1  Pin 7  (+VS) → +15V
  [ ] 6.2  Pin 4  (-VS) → -15V
  [ ] 6.3  Add 0.1 µF cap: +VS to GND (close to pin 7)
  [ ] 6.4  Add 0.1 µF cap: GND to -VS (close to pin 4)
  [ ] 6.5  Add 10 µF tantalum: +VS to GND (bulk decoupling)

  Signal (unity gain follower):
  [ ] 6.6  Pin 3  (IN+) → CD2 (divider output)
  [ ] 6.7  Pin 2  (IN-) → Pin 6 (OUT) (feedback for unity gain)
  [ ] 6.8  Pin 6  (OUT) → TPD4E1B06 Pin 1 (IO1)

  Unused pins:
  [ ] 6.9  Pins 1, 5, 8 → No connection

--- SECTION 7: TPD4E1B06 ESD PROTECTION --------------------------------------

Mount TPD4E1B06 on SOT-363 breakout board.

  [ ] 7.1  Pin 1  (IO1) → OPA828 output (pin 6)
  [ ] 7.2  Pin 3  (GND) → GND bus
  [ ] 7.3  Pin 6  (VCC) → +5V
  [ ] 7.4  Add 0.1 µF cap: VCC to GND (close to pins 6 and 3)
  [ ] 7.5  Pins 2, 4, 5 (IO2, IO3, IO4) → No connection

  Protected output:
  [ ] 7.6  Pin 1  (IO1) continues to → MUX36D08 S6 input
           (IO1 is both input from OPA828 and output to MUX36D08)

--- SECTION 8: MUX36D08 (8:1 Input Mux, existing in system) -----------------

  Enable (hardwired ON, active HIGH):
  [ ] 8.1  MUX36D08 EN → VDD (+5V or appropriate supply)

  Address lines (to Teensy):
  [ ] 8.2  MUX36D08 A0 → Teensy Pin 5
  [ ] 8.3  MUX36D08 A1 → Teensy Pin 6
  [ ] 8.4  MUX36D08 A2 → Teensy Pin 7

  HV divider input:
  [ ] 8.5  MUX36D08 S6 → TPD4E1B06 Pin 1 (IO1) / OPA828 output

--- SECTION 9: GROUND BUS ----------------------------------------------------

  [ ] 9.1  Create ground bus on stripboard
  [ ] 9.2  CD7 → GND bus
  [ ] 9.3  MUX36D04 pin 15 (GND) → GND bus
  [ ] 9.5  OPA828 ground reference → GND bus
  [ ] 9.6  TPD4E1B06 pin 3 (GND) → GND bus
  [ ] 9.7  MUX36D08 EN → VDD (hardwired ON, active high)
  [ ] 9.8  HV return (HV-) → GND bus
  [ ] 9.9  GND bus → Teensy GND
  [ ] 9.10 GND bus → System/chassis ground

--- SECTION 10: POWER SUPPLY -------------------------------------------------

  +15V rail:
  [ ] 10.1 +15V → MUX36D04 pin 14 (VDD)
  [ ] 10.2 +15V → MUX36D04 pin 2 (EN) (active high, hardwired ON)
  [ ] 10.3 +15V → OPA828 pin 7 (+VS)

  -15V rail:
  [ ] 10.4 -15V → MUX36D04 pin 3 (VSS)
  [ ] 10.5 -15V → OPA828 pin 4 (-VS)

  +5V rail:
  [ ] 10.5 +5V → TPD4E1B06 pin 6 (VCC)

--- SECTION 11: TEENSY CONTROL WIRES (5 total) --------------------------------

  MUX36D08 (input channel select):
  [ ] 11.1 Teensy Pin 5  → MUX36D08 A0
  [ ] 11.2 Teensy Pin 6  → MUX36D08 A1
  [ ] 11.3 Teensy Pin 7  → MUX36D08 A2

  MUX36D04 (divider tap select):
  [ ] 11.4 Teensy Pin 26 → MUX36D04 A0 (pin 1)
  [ ] 11.5 Teensy Pin 27 → MUX36D04 A1 (pin 16)

================================================================================
                    PRE-POWER CHECKS
================================================================================

  [ ] 12.1  No shorts: +15V to GND (>1MΩ)
  [ ] 12.2  No shorts: -15V to GND (>1MΩ)
  [ ] 12.3  No shorts: +15V to -15V (>1MΩ)
  [ ] 12.4  No shorts: +5V to GND (>1MΩ)
  [ ] 12.5  No shorts: HV+ to GND (>1MΩ)
  [ ] 12.6  Verify MUX36D04 orientation on breakout
  [ ] 12.7  Verify OPA828 orientation on breakout
  [ ] 12.8  Verify TPD4E1B06 orientation on breakout
  [ ] 12.9  Verify DA-DB bridge wire on MUX36D04
  [ ] 12.10 Verify OPA828 feedback (IN- tied to OUT)
  [ ] 12.11 Fuse installed
  [ ] 12.12 All bypass caps in place

================================================================================
                    INITIAL POWER-ON TESTS
================================================================================

Power-on sequence: +5V first, then ±15V, then enable HV.

  [ ] 13.1  Apply +5V only: TPD4E1B06 draws <1mA
  [ ] 13.2  Apply ±15V: MUX36D04 draws <1mA quiescent
  [ ] 13.3  Apply ±15V: OPA828 draws quiescent current (~10mA typ)
  [ ] 13.4  Probe OPA828 output with no input: should be near 0V
  [ ] 13.5  Set MUX36D04 address to 3 (spare): verify no signal path
  [ ] 13.6  Set MUX36D04 address to 0: verify AB3-CD3 bridged (<100Ω via DA+DB)
  [ ] 13.7  Set MUX36D04 address to 1: verify AB4-CD4 bridged
  [ ] 13.8  Set MUX36D04 address to 2: verify AB5-CD5 bridged

================================================================================
                    DIVIDER RATIO VERIFICATION
================================================================================

Using known voltage source (e.g., precision 10V calibrator):

  [ ] 14.1  Address 0 (÷10):   Apply 10V → expect ~1V at OPA828 output
  [ ] 14.2  Address 1 (÷100):  Apply 10V → expect ~100mV at OPA828 output
  [ ] 14.3  Address 2 (÷1000): Apply 10V → expect ~10mV at OPA828 output
  [ ] 14.4  Record actual ratios for firmware calibration constants

================================================================================
                    SIGNAL CHAIN INTEGRITY
================================================================================

  [ ] 15.1  Verify OPA828 output tracks CD2 (divider output)
  [ ] 15.2  Verify TPD4E1B06 output matches OPA828 output (no clipping)
  [ ] 15.3  Verify MUX36D08 S6 passes signal to preamp when selected
  [ ] 15.4  Verify no oscillation on OPA828 (check with scope, >50 MHz BW)
  [ ] 15.5  Measure leakage: disable MUX36D08, check for signal bleed

================================================================================
                    NOTES & WARNINGS
================================================================================

HIGH VOLTAGE SAFETY:
  - Maximum input: ±5000V DC (with ÷1000 divider)
  - Always use HV probe and proper PPE
  - Verify HV source is off and discharged before touching
  - Maintain creepage: >1mm per 100V on stripboard
  - Keep HV traces well separated from low-voltage circuitry

OPA828 STABILITY:
  - OPA828 has 1.5 GHz GBW - may oscillate with capacitive loads
  - Keep output trace to TPD4E1B06/MUX36D08 short
  - If oscillation occurs, add 10-50Ω series resistor at OPA828 output
  - Input capacitance of MUX36D04 drains adds to load

MUX36D04 LEAKAGE:
  - Rated <1pA at 25°C - critical for nanovolt measurements
  - Avoid flux residue on mux signal pins (clean with IPA)
  - Temperature affects leakage exponentially - keep cool

STRIPBOARD CONSIDERATIONS:
  - Cut copper strips between adjacent signal traces to prevent leakage
  - Consider guard rings around sensitive nodes (CD2, OPA828 input)
  - Use Teflon standoffs if possible for high-impedance nodes

================================================================================
                           END OF CHECKLIST
================================================================================

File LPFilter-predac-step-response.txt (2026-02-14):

t[s],f(t)
0,1.1102230246252E-16
0.033333333333333,0.0022418838736762
0.066666666666667,0.0086145165416166
0.1,0.0186204236477
0.13333333333333,0.031802699662798
0.16666666666667,0.04774240547366
0.2,0.066056094861254
0.23333333333333,0.086393466092251
0.26666666666667,0.10843513472659
0.3,0.13189052365417
0.33333333333333,0.15649586631156
0.36666666666667,0.1820123189924
0.4,0.20822417814994
0.43333333333333,0.23493719859496
0.46666666666667,0.26197700851439
0.5,0.28918761727341
0.53333333333333,0.31643001201496
0.56666666666667,0.34358083913321
0.6,0.37053116677038
0.63333333333333,0.39718532456791
0.66666666666667,0.4234598169916
0.7,0.44928230664538
0.73333333333333,0.47459066408819
0.76666666666667,0.49933208077221
0.8,0.52346224182751
0.83333333333333,0.54694455552776
0.86666666666667,0.56974943638151
0.9,0.59185363890593
0.93333333333333,0.613239639251
0.96666666666667,0.63389506195386
1,0.65381214921412
1.0333333333333,0.67298727018999
1.0666666666667,0.69142046792398
1.1,0.70911504161269
1.1333333333333,0.72607716204011
1.1666666666667,0.74231551809548
1.2,0.75784099239685
1.2333333333333,0.77266636413792
1.2666666666667,0.78680603737058
1.3,0.80027579302649
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

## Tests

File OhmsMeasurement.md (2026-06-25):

# Ohms Measurement Methodology

This document describes the resistance measurement method used in
OpenSourceDiffVM-RevB. The method is **ratiometric, 4-wire-Kelvin, with
polarity-reversed EMF cancellation** against a *manually-wired* reference
resistor. It is not a standard 2-wire / 4-wire ohmmeter and deserves its own
write-up.

For wiring and the API contract, see [`OhmsMeas.h`](OhmsMeas.h). For the
firmware command surface, see the "Ohms Mode — Manual R_ref" section in
[`CLAUDE.md`](CLAUDE.md).

## Topology

```
     V_exc (±1 V or ±2.5 V)
          │
       [SW1] ◄── polarity reversal (TMUX7234, controlled by Teensy)
          │
   ┌──── Vx2 (R_ref top sense, Kelvin)
   │
[R_ref]   ◄── manually wired into a socket; one of r1..r8 (see table below)
   │
   ├──── Vx3 (DUT high sense, Kelvin / R_ref bottom sense)
   │
[R_dut]   ◄── unknown, 4-terminal connection
   │
   ├──── Vx4 (DUT low sense, Kelvin)
   │
        GND (return)
```

All three sense points feed the high-precision front end via the MUX36D08
input mux. The current flowing through the series chain is shared between
R_ref and R_dut, so:

```
                Vx3 − Vx4         V_dut
   R_dut  =  R_ref × ─────────  =  R_ref × ─────
                Vx2 − Vx3         V_ref
```

V_exc, the polarity-switch on-resistance, and any series wiring drops all
cancel out of the ratio — only the calibrated R_ref value and the four
sense voltages enter the result. This is what makes the method robust:
the entire excitation chain can drift and you still get a correct answer.

### EMF cancellation

Thermal EMFs at the Kelvin junctions are cancelled by measuring each sense
voltage at **both excitation polarities** and forming `(V+ − V−)/2`. The
firmware handles this automatically; pass `--no-emf-cancel` to skip it for
speed.

### Signal-chain zero offset

Each sense voltage has the auto-zero offset subtracted
(`OhmsMeasApi::getSignalChainOffset`). The auto-zero tracks DAC zero-code
drift (ε₀) plus the preamp chain residual via a GND-channel measurement at
the DAC null code. Removing ε₀ from each sense before forming the ratio
matters because: even though gain drift (ε₁) already cancels in
V_dut/V_ref, offset drift does not — it creates a differential error
proportional to (V_ref − V_dut)/(V_dut × V_ref). With EMF cancellation
(default) a constant offset cancels anyway; the correction mainly matters
for `--no-emf-cancel` and for keeping the ± polarity readings symmetric for
the mirror-seed bracket math. Run `zero` before precision ohms work so the
offset is current.

### Excitation magnitude

The firmware auto-selects 1 V excitation for R_ref < 500 Ω (just r2 in
the current jig) and 2.5 V for everything else. This keeps R_ref
dissipation reasonable at the low-Ω end without giving up
signal-to-noise on the high-Ω end.

## Reference resistors

Five resistors are physically wired one-at-a-time into the breakout
socket. Each is identified by color band and by short alias. The
firmware tracks which one is currently installed via the `rref` CLI
command (selection is not persisted across reboots).

| Alias | Color  | R_ref (Ω) | V_exc  |
|---|---|---|---|
| r2 | black  | 200.13237 | 1.0 V  |
| r3 | yellow | 2002.03982  | 2.5 V  |
| r8 | green  | 5000.15707  | 2.5 V  |
| r4 | white  | 20000.07073 | 2.5 V  |
| r5 | blue | 50009.54528 | 2.5 V  |

Values are firmware constants in `RREF_ALIASES[]` (see the .ino source).

**2026-06-22: Full re-anchor** of all five rrefs via Keithley 2002 direct measurement
using Krasimir 1.0620233K cert and Keithley-traceable 5450 decade standards with
temperature correction applied. Formula: `R_ref_new = R_ref_old × (R_true / R_measured)`;
multiple DUT measurements averaged per rref. DUTs: 5450 190Ω/1k/1.9k/10k/19k/100k,
SR1010 1k/100k (all assigned values K2002-traceable).

**Hardware jig revisions (2026-06-05):** the original r1 (20 Ω), r6
(1.9 MΩ), and r7 (11 MΩ) were physically removed — at the
low-Ω/high-current end r1 caused TMUX charge-injection issues, and at
the high-Ω end (r5 = 200 kΩ, r6, r7) BinSrch could not converge,
likely due to AD8428 oscillation at high source impedance. The new r5
is a 50 kΩ blue resistor (was 200 kΩ blue), kept under the practical
threshold where AAF + preamp behave linearly. r8 was re-color-coded
from yellow2 to green.

The r8 5 kΩ value deliberately bridges the decade gap between r3
(2 kΩ) and r4 (20 kΩ), so the 1 kΩ–10 kΩ range is well-served at the
optimum ratio (see below) rather than at a 5× mismatch. The r5 50 kΩ
similarly bridges between r4 (20 kΩ) and the absent 200 kΩ slot.

## Choosing R_ref for a given DUT

### Principle

Let **ρ = R_dut / R_ref**. With per-sense measurement noise σ_v and a fixed
V_exc, the fractional uncertainty in R_dut propagates as:

```
   σ_R       σ_v
   ──── = ────── × √[ (1 + ρ)² · (1 + 1/ρ²) ]
   R_dut   V_exc
```

That bracket has a minimum at **ρ = 1** (where it equals 8) and grows
quadratically as ρ moves away from 1:

| ρ | bracket | σ_R penalty vs ρ=1 |
|---|---|---|
| 1.0 | 8.0 | 1.00× |
| 0.5 / 2  | 11.25 | 1.19× |
| 0.1 / 10 | 122 | 3.91× |
| 0.01/100 | ~10 000 | ~35× |

The takeaway: **pick R_ref so that R_dut is within ~10× of it.** Within a
factor of 3, you are at near-optimal precision. Outside a factor of 100,
the noise advantage of ratiometric measurement collapses.

### DUT-range guide

| Alias | R_ref | Sweet R_dut (ρ≈1) | Good range (0.1 ≤ ρ ≤ 10) | Sane usable (0.01 ≤ ρ ≤ 100) |
|---|---|---|---|---|
| r2 | 200 Ω | ~200 Ω | 20 Ω – 2 kΩ | 2 Ω – 20 kΩ |
| r3 | 2 kΩ | ~2 kΩ | 200 Ω – 20 kΩ | 20 Ω – 200 kΩ |
| r8 | 5 kΩ | ~5 kΩ | 500 Ω – 50 kΩ | 50 Ω – 500 kΩ |
| r4 | 20 kΩ | ~20 kΩ | 2 kΩ – 200 kΩ | 200 Ω – 2 MΩ |
| r5 | 50 kΩ | ~50 kΩ | 5 kΩ – 50 kΩ (Z ceiling; see below) | 500 Ω – 50 kΩ |

The "good" ranges overlap by design. For a 10 kΩ DUT you could pick r3
(ρ=5, ~3× penalty), r8 (ρ=2, ~1.2× penalty), r4 (ρ=0.5, ~1.2× penalty),
or r5 (ρ=0.2, ~1.5× penalty). Pick the one nearest ρ=1 when you have
the choice. **Practical coverage with the current jig is roughly 50 Ω
to 200 kΩ at sub-ppm precision.** Above ~50 kΩ use r4, not r5 — the
front-end source-impedance ceiling caps r5 at DUTs ≤ ~50 kΩ (see
below); r4 reaches MΩ-scale DUTs at reduced precision.

**High source impedance ceiling: Z_src = R_ref ∥ R_dut ≤ ~25 kΩ
(characterized 2026-06-10).** The noise math says r5 should be good
through 500 kΩ DUTs, but the front end has a hard stability ceiling
that the noise math knows nothing about. The AD8428 bank's input
current varies with its differential input voltage; through a high
source impedance at the sense node that variation feeds back into the
input. Loop gain scales with Z_src: harmless below ~20 kΩ, near unity
at ~30 kΩ. Consequences, measured with `dacsweep` at r5 + 100 kΩ
(Z_src ≈ 33 kΩ):

- The static chop-demod transfer compresses ~16–27×: full +FS → −FS
  transition in 1–2 DAC codes instead of the nominal ~15, even with
  100 ms of settle per half-cycle. The both-phase acceptance window is
  essentially empty.
- At normal chop cadence the kicked node locks into a chop-synchronous
  **period-2 limit cycle** (~±1.2 mV at the input, with a ~6-pair beat),
  so readings flip between soft rails of either sign. No search
  strategy converges on that, and an integration through it would be
  meaningless even if one did.
- Control: the identical sweep on a low-Z sense (Vx2) is textbook —
  16-code window, slope exactly gain 2000.

This is the same project-level constraint as voltage mode ("low source
impedance only"), now with a number attached. It is also, in hindsight,
what retired the original 200 kΩ r5 / 1.9 MΩ r6 / 11 MΩ r7 — those
could never have worked.

**Design rule:** keep **R_ref ∥ R_dut ≤ 25 kΩ** at the Vx3 node.
Since R_ref ∥ R_dut < R_ref, any R_ref ≤ 20 kΩ (r2/r3/r8/r4) satisfies
the rule for *every* DUT — for big DUTs, use r4 and accept the ρ
penalty (ρ = 50 ≈ 18× noise vs ρ = 1; still usable). r5 (50 kΩ) is
safe only for DUTs ≤ ~50 kΩ (ρ ≤ 1, Z_src ≤ 25 kΩ), where it gives the
best precision in its band. The firmware warns when
`--nominal` implies Z_src over the ceiling, and explains the ceiling
when a Vx3 search fails at R_ref ≥ 30 kΩ.

**Search improvements that came out of this investigation** (kept —
they benefit all R_refs): `meas r` seeds every BinSrch from physics
(Vx4 ≈ 0 V, Vx2 ≈ ±V_exc, Vx3 from the divider given `--nominal`, the
opposite-polarity code by mirror), bisects inside a small bracket with
flush chop pairs at normal cadence, and resets the AAF through the
preamp's linear region (input mux → GND + autozero-null DAC code) on
cold entry. Cold convergence on the low-Z senses dropped from ~17
probes to 3.

**Diagnostics** (see `help`): `dacsweep <ch> <a> <b> [step] [pairs]
[settleUs]` plots the chop window per DAC code (a == b gives a
time-series at one code); `dacset <code>` parks the DAC for scope work
with `hold`; `ohms pol +|-` / `ohms exc 1|2.5` drive the excitation
manually.

## Practical caveats outside the math

The clean ratiometric formula above hides several real-world effects that
become dominant near the ends of the range.

- **Below ~10 Ω.** Contact resistance and thermal EMF at the Kelvin posts
  start to dominate even with 4-wire sensing. r1 will measure sub-Ω DUTs
  in principle, but expect a µΩ-level noise floor and very tight settling
  requirements. Always EMF-cancel.
- **Above ~10 MΩ.** AD8428 input bias current (~50 nA typ) drops a real
  voltage across both R_ref and R_dut, biasing the result. At 100 MΩ that
  is ~5 mV → ~50 ppm error before any other consideration. Use r7 only
  when you have to, and treat results above 100 MΩ as approximate.
- **Self-heating in R_ref.** Excitation current `I = V_exc / (R_ref + R_dut)`.
  For r1 (20 Ω) at 1 V into a short-DUT condition, P_Rref = 50 mW —
  enough for the R_ref's tempco to walk the value during long
  integrations. Use shorter `--cycles` runs or let the resistor cool
  between measurements when integrating for tens of seconds.
- **Johnson noise in high-R R_ref.** `√(4 k T R · BW)` at R = 10 MΩ and
  BW = 1 Hz is ~13 µV/√Hz. The longer you integrate, the lower the
  effective bandwidth and the lower the noise — but the floor at very
  high R_ref is set by R_ref itself, not by the front end.
- **Preamp input range.** Each sense point (Vx2, Vx3, Vx4) must lie
  within ±5 V of ground for the BinSrch DAC tracker to acquire it. With
  V_exc = ±2.5 V and proper grounding this is automatic; check polarity
  wiring if BinSrch fails on one polarity.

## Verification status

First-light bringup of the OHMS-1 breakout completed **2026-05-30**. The
chain is proven to the following levels:

- **Repeatability (precision)**: sub-ppm within a fixed R_ref. Two
  consecutive measurements at cycles=50 and cycles=100 against a 9.4 kΩ
  DUT with r4 produced ratios identical to 8 decimal places
  (0.46999346). Excitation rail drift of ~1.3 ppm between the runs was
  fully cancelled by the ratiometric measurement; ratio held to ≤ 0.1
  ppm.
- **Cross-reference consistency**: 18 ppm spread between r3 (2 kΩ) and r4
  (20 kΩ) when measuring the same 9.4 kΩ DUT. Attributed to independent
  Keithley-transfer calibration uncertainty on each R_ref value, not to
  any instrument systematic. Each individual measurement was self-consistent
  to sub-ppm.
- **Absolute accuracy**: −20 ppm worst-case error vs a 9400 Ω ±0.005 %
  precision DUT (well inside the resistor's ±50 ppm tolerance window).
- **EMF cancellation**: ~60 µV of thermal asymmetry observed at the DUT
  Kelvin posts (Vx3+/Vx3− midpoint offset) absorbed cleanly by the
  polarity-reversal averaging.
- **Per-sense routing**: Vx2, Vx3, Vx4 confirmed reading the correct
  Kelvin nodes (V_R_dut + V_R_ref closes KVL against V_exc at Vx2 to
  within a few µV; Vx4 sits at ground despite current flow, confirming
  4-wire Kelvin connection integrity).

Practical implication: trust **sub-ppm relative measurements** for
trending (RTS, drift, repeat checks of a single DUT). Treat **absolute
accuracy** as bounded by the R_ref calibration — ~20 ppm with the
current Keithley transfer cal. To tighten absolute accuracy, re-cal the
R_ref bank against a single primary standard and patch `RREF_ALIASES`.

Bringup also surfaced two hardware items, both folded into
[`hardware-errata.md`](hardware-errata.md): the connector ribbon seating
issue (off-by-one row → no damage) and **OHMS-2** (TMUX7234 NO/NC
reversed vs schematic; firmware inverts `PIN_OHMS_POL` sense).

## Rule of thumb

> Pick R_ref ≈ R_dut. Within a factor of 3 you are at near-optimal
> precision; within a factor of 10 you are still excellent. Don't
> overthink it — but keep R_ref ∥ R_dut ≤ 25 kΩ: for DUTs above
> ~50 kΩ that means r4, not r5.

If you genuinely don't know R_dut yet, start with r4 (20 kΩ) at 2.5 V and
look at the V_dut / V_ref ratio in the output. The ratio tells you ρ,
which tells you which R_ref to swap in for the precision measurement.

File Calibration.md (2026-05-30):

# DiffVM Rev B — Calibration Checklist

## Measurement Equation

Every voltage reading is computed as:

```
Vx = [V_dac(code) + preamp_delta] × divider_ratio × refCorrection − autoZeroOffset
```

Where:
```
V_dac(code)    = dacCalTable[code]  (calibrated) or code × DAC_LSB_V  (nominal)
preamp_delta   = ADC_mean × ADC_LSB_V / PREAMP_GAIN
ADC_LSB_V      = (2 × ADC_VREF) / 2^24  ≈ 298.0 nV/count
refCorrection  = 1 + filterErr / NOMINAL_REF_V   (reference drift compensation)
```

**Key insight:** `V_dac` is the dominant term (nearly equals Vx); `preamp_delta` is a small
residual correction (≤ ~1 DAC LSB = 152.6 µV in steady state). Calibration requirements
are therefore very different for these two terms.

---

## Sensitivity Analysis

Errors in parameters that scale `V_dac` propagate at **full signal amplitude**.
Errors in parameters that scale only `preamp_delta` propagate at **reduced amplitude**
(≤ 152.6 µV / Vx of the full-range signal).

| Parameter | Affects | Sensitivity (nV per 1 ppm error) | Expected uncertainty | Est. error at Vx = 1 V |
|---|---|---|---|---|
| ADR1001 reference (5 V) | `V_dac` absolute scale | 1000 nV/ppm | ±200 ppm initial; ±0.05 ppm/°C | **±200 µV abs** / ±50 pV/°C |
| DAC INL (uncalibrated) | `V_dac` nonlinearity | up to ±10 LSB = ±1.526 mV | ±10 LSB typ (AD5760) | **±1.526 mV** |
| DAC INL (with cal table) | `V_dac` residual | noise-limited | few nV averaged | ±few nV |
| HV divider ratio (÷10, 10 V in) | `Vx` output scale | 10,000 nV/ppm | component tolerances, need measurement | TBD |
| HV divider ratio (÷108.76, 100 V in) | `Vx` output scale | 100,000 nV/ppm | nominal from Caddock specs, unverified | TBD |
| HV divider ratio (÷984.65, 1 kV in) | `Vx` output scale | 1,000,000 nV/ppm | nominal, unverified | TBD |
| Zero offset (no auto-zero) | additive offset | N/A (additive) | ±10 – 100 µV from preamp + mux offsets | **±10 – 100 µV** |
| Zero offset (with auto-zero) | additive offset residual | N/A (additive) | ±few nV (noise floor of GND measurement) | ±few nV |
| PREAMP_GAIN (2000) | `preamp_delta` scale | 0.15 nV/ppm (at 1 DAC LSB delta) | ±3000 ppm (AD8428 ±0.3%) | ±450 pV |
| ADC_VREF (2.500 V) | `preamp_delta` scale | 0.15 nV/ppm (at 1 DAC LSB delta) | depends on reference source | similar to gain |
| Ref drift compensation | `V_dac` correction residual | proportional to drift rate | 10% prediction error typical | 12.5 nV at 1 ppm/min drift |
| Ref filter time constant (1.05 s) | drift prediction accuracy | proportional to drift rate | ±20% estimated | 25 nV at 1 ppm/min drift |
| DAC filter settling | transient accuracy | step-size dependent | verified to 10 ppm per comments | ±10 ppm during transitions |

**Summary ranking by impact at 1 V full-range:**

1. **ADR1001 reference absolute accuracy** — sets ppm-level absolute floor
2. **DAC INL (must calibrate)** — ±1.5 mV without the table, ±few nV with it
3. **HV divider ratios** — dominate at HV ranges; unchecked constants in firmware
4. **Zero offset** — handled by auto-zero; verify regularly
5. **Preamp gain** — 300–450 pV at 1 DAC LSB delta; matters at sub-nV goals
6. **ADC_VREF** — similar magnitude to gain error
7. **Drift compensation** — matters during temperature transients

---

## Calibration Items (Priority Order)

### CAL-01 — ADR1001 Voltage Reference (Absolute Value)  ★★★ CRITICAL

**What:** The AD5760 DAC output is ratiometric to `VREFP` (the filtered ADR1001 average at TP1).
The DAC calibration table stores voltages measured during calibration — those measurements are
only as accurate as the reference at calibration time.

**Impact:** 1 ppm reference error → 1 ppm error in all Vx readings. At 200 ppm initial tolerance,
the reference is off by up to 1 mV at 5 V — far outside the goal.

**How to calibrate:**
1. Measure TP1 (filtered reference output, the DAC VREFP) with a calibrated DC voltmeter
   traceable to a national standard (e.g., a 10 V Josephson reference or calibrated Fluke 8508A).
2. Record actual voltage, e.g. `V_ref_actual = 4.999987 V`.
3. After building the DAC calibration table (CAL-02), all table entries were measured *relative to
   this reference* and are self-consistent. No firmware constant needs to change if the table
   was built using the same reference value.
4. For absolute traceability, scale all Vx readings by `V_ref_actual / 5.000000` — or rebuild
   the DAC calibration table after the reference has been measured and stabilized.

**Firmware constant:** None directly; accuracy is embedded in the calibration table values.

**Recommended interval:** Before each calibration table build; annually thereafter for absolute work.
Note: ADR1001 is specified 0.05 ppm/°C, so 10 °C ambient change causes 500 pV at 1 V — acceptable
for most work but measure the reference when highest absolute accuracy is needed.

---

### CAL-02 — DAC INL Calibration Table  ★★★ CRITICAL

**What:** The 16,384-point table `dacCalTable` maps each 4th DAC code (14-bit index) to an actual
measured output voltage, correcting AD5760 integral nonlinearity (INL typ ±3 LSB, max ±10 LSB).
Without the table the firmware uses `code × DAC_LSB_V` (nominal), which can be off by ±1.5 mV.

**Impact:** The DAC sets the coarse measurement value. ±1.5 mV uncalibrated is catastrophic
for a nV-level instrument. With the table, the error is limited by ADC noise during calibration
(achieves ±few nV with sufficient averaging).

**Current state:** The table is initialized to nominal values at boot (`dacCalTable.isValid()`
returns `false`). If a previous `cal save` was run with a valid table, it is automatically
restored from LittleFS flash on boot.

**Build commands (implemented):**

`cal build dac` — automatic anchor calibration (no external source needed):
- Switches to the GND input; binary-searches DAC to zero-crossing; sweeps ±2 table entries
  around the convergence code (5 entries total); measures actual V_dac at each code.
- Switches to VrefRaw (~5 V); binary-searches DAC; sweeps ±2 entries around that code.
- Marks the table valid and saves to flash automatically.
- Coverage: ~5 points near 0 V + ~5 points near 5 V. Corrects DAC zero offset and full-scale
  gain. Duration: < 5 seconds.

`cal point <voltage>` — capture a single entry from a known external voltage applied to Vx:
- User applies an accurate known voltage to the Vx input terminal.
- Firmware binary-searches DAC to lock onto the applied voltage.
- Accumulates 20 chopped measurements; stores `V_dac = V_known − ADC_residual/PREAMP_GAIN`
  at the current DAC code.
- Repeat at different voltages across ±5 V to fill in the full table.
- Call `cal save` when finished to persist the updated table.

**Typical workflow:**
```
cal build dac              # Quick auto-cal at 0 V and 5 V anchors; saves automatically
# (optional: apply external source at multiple voltages for full-range INL correction)
cal point 1.000000         # Apply 1.000000 V to Vx, then run this
cal point 2.000000         # Apply 2.000000 V to Vx, then run this
# ... repeat at -5, -4, -3, -2, -1, 0, 1, 2, 3, 4, 5 V etc.
cal save                   # Persist all point entries to flash
```

**Measurement window constraint:** The preamp clips when |Vx − V_dac| > ~1 mV. Each `cal point`
call can only store one table entry (the code the DAC locked to). To cover the full ±5 V range,
~16,380 separate measurements would be needed — in practice, a `diffvm.py` script stepping an
external calibrated source handles this automatically.

**Sparse calibration: interpolating between cardinal points.** If you do not have an automated
sweep and instead measured ~30 representative ("cardinal") points across the range, you can
piecewise-linearly fill in the rest:

```
cal cardinals      # list every operator-set point with idx, code, voltage, residual µV
cal clear <code>   # remove a bad cardinal (e.g. 'cal clear 19664' if its residual is way out)
cal interpolate    # linearly interpolate between adjacent cardinals; extrapolates outside
                   # the cardinal range using the slope of the nearest pair
cal save           # persist the now-fully-populated table to flash
```

`cal cardinals` is non-destructive and can be re-run any time. After `cal interpolate`, every
slot is non-nominal so the cardinal set effectively becomes "all slots" — to refine, run
`cal load` (reverts to the saved state) before re-interpolating.

**Choosing where to put cardinal points:** the DAC INL is roughly cubic, so place a cardinal
near each end of travel (±5 V), one near zero, and the rest spaced more densely where the INL
gradient is largest (typically near the rails). 30 well-chosen points typically give residual
INL well below ±10 µV across the range; the residual scales with the *missing curvature* of
the actual INL curve at the gaps between cardinals.

**Firmware constants used (nominal table initialization):**
```cpp
static constexpr double DAC_LSB_V = (2.0 * DAC_VREF) / DAC_FSR_CODES;  // ~152.59 µV
static constexpr double DAC_VREF  = 5.0;  // Update if reference measurement shows different value
```

**Recommended interval:** After initial build, rebuild if reference is serviced, or annually.

---

### CAL-02a — Keithley-validated DAC table refinement (`cal verify` / `cal smooth`)  ★★★ CRITICAL

**What:** After the bulk DAC table is built (CAL-02), `cal verify` walks through a default
list of 25 target voltages (±5, ±4, ±3, ±2.5, ±2, ±1, ±0.5, ±0.1, ±0.05, ±0.01, ±0.005,
±0.001, 0 V) and uses a Keithley 2002 (or any traceable DMM) as a second reference to spot-check
the calibration. Setup: a precision source (Fluke calibrator) drives the DiffVM `Vx2` input;
the Keithley measures that same input. The firmware sets a *deterministic* 14-bit-aligned DAC
code at each target (no binary search — so the same target always lands on the same code
between runs), runs a full-length chop measurement, computes DiffVM's reported `Vx`, and asks
you to type the Keithley reading. If DiffVM disagrees with Keithley by more than `--thresh`
(default 10 µV), the cal table entry at that code is overwritten with the value that would
make DiffVM match Keithley:
```
vDac_new = V_keithley − (adcMean × ADC_LSB_V / PREAMP_GAIN)
```
Within-threshold targets are kept as-is — most points should pass, and the cal table is only
touched where it's genuinely wrong.

**Why a separate command from `cal point`:** `cal point` uses `binarySearchDAC()` to lock onto
a known voltage, then stores the measured DAC residual. That's fine for *building* a table but
non-deterministic for re-verification — the code it converges to depends on noise and starting
state. `cal verify` instead picks the DAC code by deterministic rounding, accepts the operator's
Keithley reading as the trusted absolute value, and only updates the table when the existing
entry is wrong by more than threshold.

**Workflow per target:**
1. Firmware prints `[i/25] Target +0.05 V, DAC code 328 (V_nom = +0.050033 V). Apply ~0.05 V; enter Keithley reading (V) or s/a/q:`.
2. You dial the Fluke near 0.05 V, read the Keithley (e.g. `0.049902`), type that into the firmware.
3. Firmware runs ~285 chop cycles (≈15 s, configurable via `--cycles N`) at the deterministic DAC code.
4. It prints DiffVM, Keithley, and diff in µV. Either reports "OK: within ±10 µV — no update" or "Updated cardinal[code]: was X, now Y (Δ = Z µV)".
5. **Smoothing between targets:** every time a target is confirmed (Updated *or* Within-threshold) the firmware linearly interpolates the slots between the previous confirmed target and the current one. This keeps the table self-consistent across the verified range and prevents the discontinuities that `interpolateGaps()` can't fix once the table is dense (`MAX_CARDINALS=256` cap is bypassed by `interpolateBetweenCodes`).
6. Single-letter commands at the prompt: `s` skip this target, `a` abort (no save), `q` quit + smooth + suggest save.

**Commands:**
```
cal verify                                    # interactive, default 25 targets, 10 µV thresh, ~15 s/target
cal verify --thresh 5                         # tighter threshold for a follow-up refinement pass
cal verify --cycles 50                        # quick pass (~3 s/target) before a careful one
cal verify 0.05 0.1 0.5                       # override target list
cal save                                      # persist the updated table to flash
```

**`cal smooth` — post-hoc fix without the Keithley:** if a verify session was saved before the
inter-target smoothing was implemented (or if the session was interrupted partway), the saved
table can have correct cardinal values at the verify codes surrounded by stale cal-build-dac
interpolation on either side. Symptom: `cal cardinals` shows residual spikes at the verify
codes (30–130 µV jumps relative to neighbours). Fix with no measurement:
```
cal smooth        # blends slots between consecutive default verify-target codes
cal smooth 0.05 0.1   # blend just one pair (e.g. if only two cardinals are isolated)
cal save          # persist
```
This reuses the existing cardinal values at each target as fixed endpoints and linearly blends
everything between them. Safe to run with the Keithley turned off.

**Implementation notes:**
- The verify workflow lives in its own module: `CalVerify.h` / `CalVerify.cpp`, decoupled from
  the .ino through a `CalVerifyApi` function-pointer struct (no direct dependency on
  `DacCalibrationTable` or other internal types).
- `DacCalibrationTable::interpolateBetweenCodes(lo, hi)` is the linear-blend primitive used by
  both `cal verify` (mid-session) and `cal smooth` (post-hoc). Operates on the exact code range
  specified, so it's unaffected by `MAX_CARDINALS=256`.
- The default target list `kCalVerifyDefaultTargets[]` is exported from `CalVerify.h` so
  `cal smooth` and `cal verify` use the exact same codes.
- The calibration input is `Vx2` (separate from the normal Vx1 measurement port) so the
  Keithley/Fluke setup can stay wired during normal use.

**Recommended interval:** Run `cal verify` after every `cal build dac` to validate the dense
table against an independent reference; re-run annually or after the Keithley is recertified.
Run `cal smooth` only as a one-shot recovery for an interrupted verify session.

---

### CAL-03 — Zero Offset (Auto-Zero)  ★★★ CRITICAL

**What:** `performAutoZero()` measures the GND input channel, extracts the full-chain offset
(preamp DC offset, MUX charge injection residuals, PCB thermal EMFs, DAC zero error), and stores
it in `scanner.autoZeroOffset`. All subsequent Vx readings subtract this value.

**Impact:** Without auto-zero: the preamp and mux offset contributions can be 10–100 µV.
Chopping eliminates most preamp offset and 1/f noise, but thermal EMFs and DAC zero offsets
persist. Even 100 nV of uncorrected offset is 100 nV absolute error.

**Current state:** Implemented and functional. Auto-zero runs:
- Manually: `zero` command
- Automatically: every `autoZeroInterval` scan sweeps (default 10, configurable with `autozero interval N`)
- Enable/disable: `autozero on|off`

**Not persisted:** `autoZeroOffset` is stored in RAM and lost on reboot. A first `zero` run
after boot is mandatory before trusting any readings.

**Verification:**
1. After auto-zero, switch to GND channel (`scan add GND`) and verify reading ≈ 0 ± noise floor.
2. Typical residual should be < ±10 nV (noise limited at 20 chop cycles, ~1 µV/√(20)
   divided by the √N improvement).

**Recommended interval:** Every measurement session start; automatically every few minutes during
long runs (thermal EMFs change with environment temperature).

---

### CAL-04 — HV Divider Ratios  ★★ HIGH (HV ranges only)

**What:** Firmware uses runtime-adjustable constants for the three HV divider ratios
(initialized to calculated defaults at boot; overridden from flash if `cal save` was run):
```cpp
static double DIVIDER_RATIO_10   = 10.0;      // ±50V range
static double DIVIDER_RATIO_100  = 108.76;    // ±500V range (calculated from Caddock specs)
static double DIVIDER_RATIO_1000 = 984.65;    // ±5kV range (calculated from Caddock specs)
```

`DIVIDER_RATIO_100` and `DIVIDER_RATIO_1000` are calculated from nominal Caddock 1776-C4815
resistor segment values. Actual values depend on:
- Caddock resistor ratios (specified ±0.01% matching, but absolute resistance has tolerance)
- MUX36D04 on-resistance (~250 Ω modeled in firmware, varies with process)
- PCB trace resistance at the junction points

**Impact:** A 100 ppm ratio error at the ÷108.76 range (measuring 100 V) = 10 µV at 1 V referred
to input — dominates all other error sources for HV operation.

**How to calibrate:**
1. Apply a known accurate voltage in the ÷10 range (e.g., from a calibrated 10 V source at TP-HV).
2. Compare the DiffVM reading to the known voltage; compute the actual ratio.
3. For ÷100 and ÷1000, apply voltages at 10× and 100× respectively with known accuracy and
   compute actual ratios.

Alternatively, cross-calibrate using the ±5V range: apply exactly 10 V (or 100 V, 1000 V) to the
HV input and compare the HV-range reading to a direct ±5V measurement of a /10 (or /100, /1000)
attenuated version using a calibrated resistive divider.

**Firmware update:** Use serial commands — no recompile needed:
```
cal set div10  <measured_ratio>
cal set div100 <measured_ratio>
cal set div1000 <measured_ratio>
cal save
```
Values persist in LittleFS flash and reload automatically on boot.

**Recommended interval:** Before first HV measurements; annually or after component replacement.

---

### CAL-04a — OPA828 Buffer Offset  ★★ HIGH (HV ranges only)

**What:** The HV divider output is buffered by an OPA828 voltage follower before the MUX36D08
input multiplexer. The OPA828 input offset voltage (VOS) adds a fixed DC error to every HVDiv
measurement. Typical VOS is a few to tens of µV; the production maximum is 150 µV at 25°C.

**Why chopping does not help:** The TMUX7234 chopper switches sit *after* the OPA828 in the signal
path. Chopping toggles signal polarity at the TMUX, so only offsets that appear after that point
(i.e., in the AD8428 preamp chain) are cancelled. The OPA828 offset passes through the chopper
unchanged, appearing as a fixed DC error in `vxAtPreamp`.

**Signal path:**
```
HV Input → Caddock divider → [OPA828 + VOS] → TPD4E1B06 → MUX36D08 S6 → TMUX (chop) → AD8428 → ADC
                                  ↑ error here — not cancelled by chopping
```

**Impact on measurement accuracy:**

The offset is at the OPA828 output and is multiplied by the active divider ratio in the final result:

| Range | Ratio | 16 µV offset → input-referred error |
|---|---|---|
| ±50V (÷10) | 10.0 | **160 µV** |
| ±500V (÷108.76) | 108.76 | **1.74 mV** |
| ±5kV (÷984.65) | 984.65 | **15.8 mV** |

The ÷10 range is most affected. At ÷100 and ÷1000 the input-referred impact is negligible
relative to full scale, but the OPA828 offset itself should still be corrected for completeness.

**How the correction is applied in firmware:**

In `computeInputVoltage()`, when channel == `HVDiv`, `OPA828_OFFSET` is subtracted from
`vxAtPreamp` before multiplying by the divider ratio:

```
Vx = (vxAtPreamp − OPA828_OFFSET) × dividerRatio
```

**Measurement procedure:**

1. Short the HV divider input to ground (or connect a stable, known-zero source).
2. Select the ÷10 range (`divider 10`).
3. Allow the measurement to stabilize (15–30 minutes of thermal warm-up recommended).
4. Record the displayed voltage; divide by the divider ratio to get the raw offset:
   ```
   OPA828_OFFSET = displayed_voltage / DIVIDER_RATIO_10
   ```
   Example: display reads 160 µV → OPA828_OFFSET = 160 µV / 10 = **16 µV = 0.000016 V**.
5. Apply and save:
   ```
   cal set opa828 0.000016
   cal save
   ```
6. Verify: re-measure with HV input grounded — reading should be near zero (noise floor).

**Temperature drift:** The OPA828 typical offset TC is 1.8 µV/°C. A 10°C warm-up from cold start
changes the offset by ~18 µV. At ÷10 this is 180 µV referred to input. For best results, measure
the offset after the board has thermally stabilised (typically 15–30 minutes after power-on), and
re-calibrate if the ambient temperature changes by more than a few degrees.

**Firmware update:** No recompile needed:
```
cal set opa828 <value_in_volts>    (e.g. 0.000016 for 16 µV)
cal save
```

Persisted in `/cal_consts.bin` (v2 format). On first load of a v1 file, defaults to 0.0 V.

**Recommended interval:** At initial commissioning after thermal stabilisation; re-measure if the
OPA828 is replaced or if ambient temperature changes significantly.

---

### CAL-05 — Preamp Gain (PREAMP_GAIN)  ★ MEDIUM

**What:** `PREAMP_GAIN = 2000.0` scales the ADC residual back to an input voltage:
```
preamp_delta = ADC_mean × ADC_LSB_V / PREAMP_GAIN
```
This term is the small correction between the DAC coarse voltage and the true Vx.

**Impact:** With the DAC binary-search tracking Vx to within ≤1 DAC LSB (152.6 µV), the
worst-case preamp_delta is ±152.6 µV. The AD8428 gain accuracy is ±0.3% (3000 ppm), giving:

```
Error = 3000 ppm × 152.6 µV = 458 pV
```

For 8.5-digit operation (≈3 nV at 1 V), this is well within budget.
For 9.5-digit operation (≈0.3 nV at 1 V), it contributes ~1.5× the noise floor but is still
acceptable since preamp_delta is typically much less than 1 DAC LSB when Vx is stable.

**How to measure:** Apply a known accurate voltage Vx (e.g., 1.000 000 0 V from a calibrated source
or Josephson reference). With the DAC calibration table active and a good auto-zero, the residual
`preamp_delta` term can be extracted by comparing readings with PREAMP_GAIN set to 2000 vs.
an externally measured gain value.

Alternatively, directly measure the closed-loop gain of the AD8428 chain by applying a known
differential input and measuring the output with a calibrated oscilloscope or ADC.

**Firmware update:** Use serial commands — no recompile needed:
```
cal set gain <measured_gain>
cal save
```
Value persists in LittleFS flash and reloads automatically on boot.

**Recommended interval:** At initial commissioning. Re-measure if AD8428s are replaced.

---

### CAL-06 — ADC Reference Voltage (ADC_VREF)  ★ MEDIUM

**What:** `ADC_VREF = 2.500` V sets the ADS127L11 full-scale range for the ADC:
```
ADC_LSB_V = (2 × ADC_VREF) / 2^24 ≈ 298.023 nV/count
```
This affects only `preamp_delta` (same as PREAMP_GAIN above).

**Note on reference source:** Confirm which component drives ADS127L11 VREF pin (check schematic
`DAC.kicad_sch`). If it is derived from the same ADR1001 chain as the DAC reference, then:
- ADC_VREF and DAC_VREF drift together, and their ratio is stable
- Reference absolute drift is handled by the drift compensation system
- Residual error from ADC_VREF inaccuracy is small

If ADC VREF comes from a *separate* component, measure it directly and update the constant.

**Impact:** Same order as PREAMP_GAIN error: at 1 DAC LSB preamp_delta and 1000 ppm ADC_VREF
error → 152.6 µV × 1000 ppm = 152.6 pV. Acceptable for most purposes.

**Firmware update:**
```cpp
static constexpr double ADC_VREF = 2.500;  // Replace with measured value if separate reference
```
Note: changing `ADC_VREF` also changes `ADC_LSB_V` (derived constant) automatically.

**Recommended interval:** At initial commissioning. Rarely needs updating if sharing ADR1001 chain.

---
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

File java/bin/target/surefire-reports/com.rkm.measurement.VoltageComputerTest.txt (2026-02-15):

-------------------------------------------------------------------------------
Test set: com.rkm.measurement.VoltageComputerTest
-------------------------------------------------------------------------------
Tests run: 13, Failures: 0, Errors: 0, Skipped: 0, Time elapsed: 0.031 s -- in com.rkm.measurement.VoltageComputerTest

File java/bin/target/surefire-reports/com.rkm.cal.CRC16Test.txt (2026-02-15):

-------------------------------------------------------------------------------
Test set: com.rkm.cal.CRC16Test
-------------------------------------------------------------------------------
Tests run: 6, Failures: 0, Errors: 0, Skipped: 0, Time elapsed: 0.137 s -- in com.rkm.cal.CRC16Test

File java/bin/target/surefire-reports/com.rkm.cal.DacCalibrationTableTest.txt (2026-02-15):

-------------------------------------------------------------------------------
Test set: com.rkm.cal.DacCalibrationTableTest
-------------------------------------------------------------------------------
Tests run: 8, Failures: 0, Errors: 0, Skipped: 0, Time elapsed: 0.044 s -- in com.rkm.cal.DacCalibrationTableTest

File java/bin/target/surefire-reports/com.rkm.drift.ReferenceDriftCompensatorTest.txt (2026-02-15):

-------------------------------------------------------------------------------
Test set: com.rkm.drift.ReferenceDriftCompensatorTest
-------------------------------------------------------------------------------
Tests run: 8, Failures: 0, Errors: 0, Skipped: 0, Time elapsed: 0.046 s -- in com.rkm.drift.ReferenceDriftCompensatorTest

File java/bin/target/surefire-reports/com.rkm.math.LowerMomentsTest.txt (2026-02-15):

-------------------------------------------------------------------------------
Test set: com.rkm.math.LowerMomentsTest
-------------------------------------------------------------------------------
Tests run: 7, Failures: 0, Errors: 0, Skipped: 0, Time elapsed: 0.023 s -- in com.rkm.math.LowerMomentsTest

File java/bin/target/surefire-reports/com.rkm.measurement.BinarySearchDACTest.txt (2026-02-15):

-------------------------------------------------------------------------------
Test set: com.rkm.measurement.BinarySearchDACTest
-------------------------------------------------------------------------------
Tests run: 11, Failures: 0, Errors: 0, Skipped: 0, Time elapsed: 0.246 s -- in com.rkm.measurement.BinarySearchDACTest

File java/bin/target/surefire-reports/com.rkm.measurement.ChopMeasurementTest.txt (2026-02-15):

-------------------------------------------------------------------------------
Test set: com.rkm.measurement.ChopMeasurementTest
-------------------------------------------------------------------------------
Tests run: 5, Failures: 0, Errors: 0, Skipped: 0, Time elapsed: 0.020 s -- in com.rkm.measurement.ChopMeasurementTest

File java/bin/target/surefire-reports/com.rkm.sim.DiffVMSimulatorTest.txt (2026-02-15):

-------------------------------------------------------------------------------
Test set: com.rkm.sim.DiffVMSimulatorTest
-------------------------------------------------------------------------------
Tests run: 7, Failures: 0, Errors: 0, Skipped: 0, Time elapsed: 0.033 s -- in com.rkm.sim.DiffVMSimulatorTest

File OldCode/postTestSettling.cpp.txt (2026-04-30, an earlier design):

// ===== POST Test 10: Settling time / ENOB =====================================
// REMOVED 2026-04-30 — preserved here for reference. Was the last entry in runPOST().
// Drives the input mux to GND and the DAC between its largest non-overflowing
// positive code (maxCode) and most negative non-overflowing code (minCode), with
// a chopper toggle in between. After each transition the ADC is read until 5
// consecutive samples lie within SETTLE_TOL_LSB of each other; the population
// stdev of those 5 samples is the within-run plateau noise. Averaged over
// SETTLE_TRIALS trials per phase, the noise is converted to ENOB; PASS if all
// four phases >= 20 bits.

namespace post_settling {
  static constexpr int      SETTLE_TRIALS         = 5;
  static constexpr int      SETTLE_MAX_SAMPLES    = 200;     // ~51 ms cap
  static constexpr int32_t  SETTLE_TOL_LSB        = 64;      // last-PLATEAU_N stability band
  static constexpr int32_t  OVERFLOW_BACKOFF_LSB  = 200000;  // headroom below ADC_OVERFLOW_POS
  static constexpr float    ENOB_PASS_BITS        = 20.0f;
  static constexpr int      PLATEAU_N             = 5;
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

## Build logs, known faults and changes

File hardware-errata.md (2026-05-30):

# DiffVM Rev B — Hardware Errata

This document records deviations between the physical assembled Rev B board
and the KiCad schematic / PCB files in `DiffVM/` (`DiffVM_4L.kicad_sch`,
`DiffVM_4L.kicad_pcb`, and per-sheet `FrontEnd.kicad_sch`, `DAC.kicad_sch`,
`VRef.kicad_sch`). Each entry should be folded back into the schematic
before the next board revision is fabricated.

## Index

| ID | Subsystem | Summary |
|----|---|---|
| [DAC-1](#dac-1) | AD5760 output Sallen-Key filter | Resistor values reduced; filter now underdamped |
| [PREAMP-1](#preamp-1) | AD8428 input RFI filter | 33 nF differential + 1 µF Vcm caps added |
| [ADC-1](#adc-1) | ADS127L11 anti-alias filter (C19) | 22 nF → 47 nF |
| [ADC-2](#adc-2) | ADS127L11 VREFP series resistor | 50 Ω added in series |
| [REF-1](#ref-1) | VrefRaw routing (J3 → MUX S3) | Unbuffered output sags under preamp loading; buffer required |
| [IC-1](#ic-1) | U3 op-amp substitution | OPA2140AID → ADA4522-2 |
| [MISC-1](#misc-1) | Other capacitor value changes | C16, C18, C54 |
| [OHMS-1](#ohms-1) | Ohms-measurement breakout (external for now, onboard for next rev) | New external breakout with ±2.5 V excitation, 2× MUX36S08 R_ref bank, TMUX7234 polarity switch, 4-wire Kelvin DUT header |
| [OHMS-2](#ohms-2) | TMUX7234 polarity switch NO/NC swap | As-built SW1 has NO/NC reversed vs schematic; firmware inverts PIN_OHMS_POL sense |

---

## Errata

### DAC-1 — AD5760 output filter resistor values  

**Location:** Sallen-Key low-pass filter on the AD5760 DAC output, upstream of
the TMUX7234 input mux (see `DAC.kicad_sch`).

| | Schematic | Actual on board |
|---|---|---|
| R (series) | 9.01 kΩ | **1.68 kΩ** |
| R (Sallen-Key feedback) | 18.0 kΩ | **3.17 kΩ** |

**Status:** The reduced resistor values changed the filter Q. Empirical
step-response measurement (augmented `postTestReferences()`, 0 → +FS step,
30 s probe window) shows the filter is now **underdamped** with ringing at
roughly 10 s period; 10 µV settling against rail-to-rail step takes ~30 s
rather than the ~75 ms expected from the original ~25 ms τ.

**Firmware impact:** `binarySearchDAC()` no longer relies on a hardcoded
RC settle time — it chops while searching so the slow ringing averages out.
`DAC_SETTLE_MIN_MS = 80` / `DAC_SETTLE_MAX_MS = 300` in `DacDriver::
calculateSettleTime()` are wildly under-budget for true 1 µV settling but
are tolerated because measurements are themselves chopped and integrated.

**Recommended fix:** Re-design the filter Q at the next board revision —
the present values are believed to be an unintended rework artifact rather
than a deliberate design choice. Until then, leave the firmware
chop-based mitigation in place.

---

### PREAMP-1 — AD8428 input RFI filter additions  

**Location:** Differential input pair of the AD8428 instrumentation amplifier,
on the preamp side of the existing 22 Ω series resistors at each input leg
(see `FrontEnd.kicad_sch`).

**Not present on schematic. Added on the board:**

| Component | Value | Function |
|---|---|---|
| Differential cap (no designator on schematic) | **33 nF** | RC differential-mode filter with the 22 Ω series resistors |
| C15 (common-mode Vcm cap) | **1 µF** | Common-mode RC filter to ground |

**Rationale:** RFI insurance. A previously-investigated 12 ms preamp swell
on the input traced to an external source (Fluke calibrator), but the
differential and Vcm caps were retained as belt-and-braces against future
RF coupling on the inputs.

**Firmware impact:** The added capacitance contributes to the post-chop-edge
settle window. `CHOP_SETTLE_US = 10000` (10 ms) in
`OpenSourceDiffVM-RevB.ino` accommodates this — see the inline comment
"`post-chop-edge settle: preamp + TMUX + AAF (τ≈56ms after 47nF cap, was 21nF)`".

---

### ADC-1 — ADS127L11 anti-alias filter cap (C19)  

**Location:** Differential anti-alias filter at the ADS127L11 input pair
(see `DAC.kicad_sch`).

| | Schematic | Actual on board |
|---|---|---|
| C19 | 22 nF | **47 nF** |

**Firmware impact:** Increases the AAF time constant. Tracked by the
comment near `CHOP_SETTLE_US` in the firmware: `τ ≈ 56 ms after 47 nF cap,
was 21 nF`. The 10 ms `CHOP_SETTLE_US` allows the AAF to settle within
each chop half-cycle.

**Status:** This is the current ADEV baseline cap value (see project memory
`project_adev_baseline_47nf.md` — 46 nV @ τ=15 s, OSR=12800, samples=14
achieved with C19 = 47 nF).

---

### ADC-2 — ADS127L11 VREFP series resistor  

**Location:** Between the 2.5 V reference output and the ADS127L11 VREFP pin
(see `DAC.kicad_sch`).

| | Schematic | Actual on board |
|---|---|---|
| Series R on VREFP | direct connection | **50 Ω** |

**Rationale:** The ADS127L11 internal reference buffer (REFP_BUF, CONFIG1
bit 3, enabled in firmware via `ADC_REFBUF_ENABLE = true`) sinks dynamic
current spikes when sampling. The series resistor decouples those spikes
from the upstream reference network so they don't perturb the filtered
ADR1001 average that drives the DAC reference.

**Firmware impact:** None directly — the REFP_BUF bit must remain enabled
to compensate for the source impedance the resistor adds.

---

### REF-1 — VrefRaw is not directly usable as a reference  

**Location:** J3 (VrefRaw, the unbuffered three-ADR1001 average upstream of
the Sallen-Key reference filter) is routed to the input multiplexer S3
channel for runtime reference-drift monitoring (see `VRef.kicad_sch` and
`FrontEnd.kicad_sch`).

**Issue:** The MUX S3 path loads VrefRaw with the preamp/mux input
impedance during measurement. The loading is enough to sag VrefRaw out of
spec — making the runtime drift measurement unreliable.

**Workaround in firmware:** `postTestReferences()` is currently bypassed in
POST. The DAC reference drift compensation system still works for the
internal path (the DAC sees TP1, the filter *output*, not VrefRaw), but
the live runtime drift measurement is disabled until a hardware fix
is in place.

**Hardware fix required:** Add a buffer (e.g. another OPA828 in voltage-
follower configuration) between J3 and the MUX S3 input. After the buffer
is installed, re-enable `postTestReferences()` and the runtime
`measureFilterError()` machinery.

---

### IC-1 — U3 op-amp substitution  

**Location:** U3 on `FrontEnd.kicad_sch` (SOIC-8 dual op-amp footprint).

| | Schematic | Actual on board |
|---|---|---|
| U3 part number | OPA2140AID | **ADA4522-2** |

**Rationale:** The ADA4522-2 is a zero-drift (chopper-stabilized) dual
precision op-amp with substantially lower offset and 1/f noise than the
OPA2140AID JFET op-amp originally specified:

| Parameter | OPA2140AID (schematic) | ADA4522-2 (actual) |
|---|---|---|
| Input offset voltage (typ) | 120 µV | **0.4 µV** |
| Offset drift (typ) | 0.35 µV/°C | **0.022 µV/°C** |
| Input voltage noise (0.1–10 Hz, p-p) | 0.25 µV | **0.117 µV** |
| Input bias current (typ) | 0.5 pA | 50 pA |
| GBW | 11 MHz | 2.7 MHz |

The substitution trades bandwidth and input bias current for ~300× better
input offset and ~16× better drift. Pin-compatible SOIC-8 dual; same
supply rails. The bias current is higher (CMOS chopper inputs vs JFET),
so the substitution is most appropriate where source impedance is moderate
and DC accuracy dominates over BW/Iib budget.

**Firmware impact:** None directly.

---

### MISC-1 — Other capacitor value changes  

These capacitor values were changed during preamp-chain tuning and
anti-alias adjustments. Their subsystem context should be confirmed
against the schematic before merging.

| Designator | Schematic | Actual on board | Subsystem (TBD — confirm) |
|---|---|---|---|
| C16 | 22 nF | **55 nF** | — |
| C18 | 22 nF | **55 nF** | — |
| C54 | 22 nF | **97 nF** | — |

C16 and C18 were changed together (same value, paired change). C54 was
changed independently.

---

### OHMS-1 — Ohms-measurement breakout (external; integrate on next rev)  

**Location:** New off-board breakout PCB; connects to DiffVM via a
10-conductor ribbon. See `docs/ohms-breakout.svg` for the full
schematic.

**Function:** Adds resistance measurement to the instrument using the
existing chop loop, preamp, DAC, and the unused Vx3 / Vx4 / Vx5 input-
MUX channels. Topology is 3-Kelvin-sense ratiometric with ±2.5 V
polarity-reversed excitation:

```
R_dut = R_ref × (Vx3 − Vx4) / (Vx5 − Vx3)
```

V_exc and the R_on of the polarity switch and Force MUX cancel out of
the ratio — the only cal'd quantities are the R_ref bank values.

**Breakout content (this revision, external):**

| Component | Role |
|---|---|
| ADA4522-2 dual op-amp | Half A = +2.5 V follower; Half B = G=−1 inverter for −2.5 V |
| Vishay VHP100 10 kΩ matched pair | Inverter gain-set, ≤2 ppm tracking |
| TMUX7234 SPDT | Polarity switch (same part as the input-chop TMUXes — already qualified) |
| 2× MUX36S08 | Force MUX + Sense MUX, both driven by the same 3 address-bit lines |
| 7× precision R_ref (20 Ω, 200 Ω, 2 kΩ, 20 kΩ, 200 kΩ, 2 MΩ, 20 MΩ) | Vishay Z-foil / Caddock USR; matches Keithley 2002 ranges for cross-validation |
| 4-terminal Kelvin binding posts | DUT under test |

**Firmware impact:** Adds new module `OhmsMeas.{h,cpp}`. New Teensy
GPIOs:

| Function | Teensy pin |
|---|---|
| Excitation polarity (SW1.IN) | 5 |
| R_ref MUX A0 (U2 & U3) | 6 |
| R_ref MUX A1 (U2 & U3) | 7 |
| R_ref MUX A2 (U2 & U3) | 8 |

New CLI: `meas r <bank_idx>`, `cal r rref`, `cal r show`.
CalibrationStore gains an `OhmsCalBlock` (version-bumped).

**Required for next PCB revision:**

1. Move the ±2.5 V generator onboard, using the spare half of the
   board's U3 (ADA4522-2 per [IC-1](#ic-1) substitution) as the
   G=−1 inverter. Add a matched-R pair (Vishay VHP100 footprint).
2. Onboard 2× MUX36S08 R_ref bank (or pull the bank to onboard with
   a smaller MUX36D04 if only 4 ranges are wanted).
3. Onboard TMUX7234 SPDT for polarity selection.
4. Dedicated 4-terminal Kelvin DUT header with separate force/sense
   pads — keep sense traces away from the force-path copper.
5. Provide Vx5 routing from the MUX36D08 S8 channel to the Sense MUX
   output.
6. Reserve Teensy pins 5/6/7/8 (or equivalent free GPIO) for the
   ohms control bus.

Until the next rev: the external breakout is documented here as the
authoritative build reference. Schematic source: `docs/ohms-breakout.svg`.

**Verification status (2026-05-30):**

First-light bringup completed. All five phases (excitation rails, polarity
switch, V_exc rail select, end-to-end against a known DUT, quantitative
accuracy) passed.

| Phase | Result |
|---|---|
| 1 Rails | 1.0 V and 2.5 V rails within spec; unloaded |
| 2 Polarity | TMUX flips cleanly; NO/NC swap discovered (see [OHMS-2](#ohms-2)) |
| 3 V_exc select | 1.0 V ↔ 2.5 V rail switch works |
| 4 / 5 Measurement | 9400 Ω ±0.005 % DUT measured against r4 = −20 ppm; against r3 = −1.8 ppm. 18 ppm R_ref-to-R_ref spread attributed to independent transfer-cal uncertainty against the Keithley reference. Sub-ppm repeatability within a fixed R_ref. EMF cancellation absorbs ~60 µV of thermal asymmetry on DUT Kelvin posts. Ratiometric rejection holds the ratio to 0.1 ppm against ~1.3 ppm V_exc drift between runs. |

Caveats discovered during bringup:
- Cable seating: an off-by-one-row Teensy↔breakout ribbon misalignment shorted
  every signal to GND. POST + adev after re-seating showed no chip damage.
- TMUX polarity: see [OHMS-2](#ohms-2).

---

### OHMS-2 — TMUX7234 polarity switch NO/NC reversed  

**Location:** SW1 (TMUX7234) on the OHMS-1 breakout, controlled by
`PIN_OHMS_POL` (Teensy pin 5). See `docs/ohms-breakout.svg` and
[OHMS-1](#ohms-1).

**Symptom (discovered during phase-1 bringup, 2026-05-30):**
With `PIN_OHMS_POL = HIGH` the SW1 common pin sources −V_exc rather than
the schematic-intended +V_exc; with `PIN_OHMS_POL = LOW` it sources
+V_exc. The NO and NC pins of the as-built SW1 are reversed relative to
the schematic.

**Status:** Accommodated in firmware rather than reworked on the
breakout. Convention:

| `PIN_OHMS_POL` | SW1 common output |
|---|---|
| **LOW** | **+V_exc** |
| HIGH | −V_exc |

Inverted in:
- `PIN_OHMS_POL` pin comment in `OpenSourceDiffVM-RevB.ino`
- `ohmsAdapter_setPolarity()` (writes `LOW` for `pos=true`)
- Setup default (`digitalWrite(PIN_OHMS_POL, LOW)` boots to +V_exc)
- `ohms pol +|−` CLI in `cmdOhms()`

EMF cancellation in `OhmsMeas::cmdMeasR` is sign-agnostic, so the
measurement math is unaffected — only the human-facing labels needed
correcting.

**Fix for next rev:** correct the NO/NC tie on the breakout silkscreen
and re-pin, then revert the firmware inversions.

---

## Status notes

- The schematic in `DiffVM/` represents Rev B as **originally designed**.
  Applying the changes above brings the schematic into agreement with the
  current physical board.
- Items DAC-1 and REF-1 are *known design issues* in addition to being
  documentation deltas — they should be redesigned, not merely transcribed,
  at the next board revision.
- Firmware compensations (chop-based settling for DAC-1, `postTestReferences`
  bypass for REF-1) should be removed in lockstep with the hardware fixes.

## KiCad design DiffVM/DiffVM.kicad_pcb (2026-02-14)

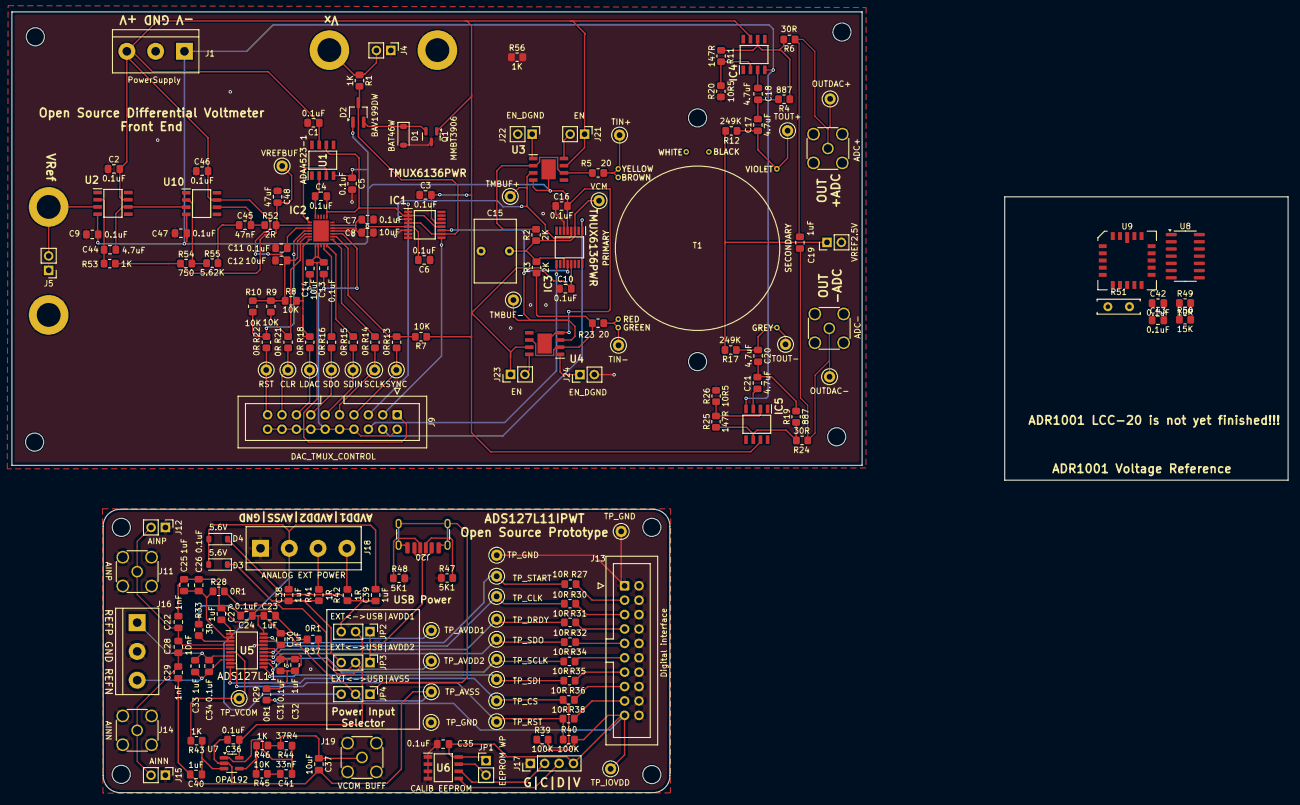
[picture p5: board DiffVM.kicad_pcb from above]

Board: 2 copper layers, 225.2 x 137.8 mm, 197 parts (0 on the bottom side), 116 nets.

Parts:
C1, C2, C3, C4, C5, C6, C7, C9, C10, C11, C13, C16, C24, C26, C31, C34, C35, C36, C42, C43, C46, C47: 0.1uF; C_0805_2012Metric_Pad1.18x1.45mm_HandSolder
C8, C12, C14, C37: 10uF; C_0805_2012Metric_Pad1.18x1.45mm_HandSolder
C15: 10uF; C_Rect_L7.2mm_W11.0mm_P5.00mm_FKS2_FKP2_MKS2_MKP2
C17, C18, C20, C21, C44: 4.7uF; C_0805_2012Metric_Pad1.18x1.45mm_HandSolder
C19, C23, C25, C27, C30, C32, C33, C38, C39, C40: 1uF; C_0805_2012Metric_Pad1.18x1.45mm_HandSolder
C22, C29: 1nF; C_0805_2012Metric_Pad1.18x1.45mm_HandSolder
C28: 10nF; C_0805_2012Metric_Pad1.18x1.45mm_HandSolder
C41: 33nF; C_0805_2012Metric_Pad1.18x1.45mm_HandSolder
C45: 47nF; C_0805_2012Metric_Pad1.18x1.45mm_HandSolder
C48: 47uF; C_0805_2012Metric_Pad1.18x1.45mm_HandSolder
D1: BAT46W; D_SOD-123
D2: BAV199DW; TSOT-23_HandSoldering
D3, D4: 5.6V; D_SOD-123
H1, H2, H3, H4, H5, H6, H7, H8, H9, H10: MountingHole; MountingHole_3.2mm_M3_DIN965
IC1, IC3: TMUX6136PWR; SOP65P640X120-16N
IC2: AD5760BCPZ; QFN50P400X500X100-25N-D
IC4, IC5: AD797; SOIC127P600X175-8N
J1: PowerSupply; TerminalBlock_bornier-3_P5.08mm
J2, J3, J6, J7: BindingPost; Binding_Post_4.2mm
J4: Vx; PinHeader_1x02_P2.54mm_Vertical
J5: VRef; PinHeader_1x02_P2.54mm_Vertical
J8: ADC+; SMA_Wurth_60312002114503_Vertical
J9: DAC_TMUX_CONTROL; IDC-Header_2x10_P2.54mm_Vertical
J10: ADC-; SMA_Wurth_60312002114503_Vertical
J11: AINP; SMA_Wurth_60312002114503_Vertical
J12: AINP; PinHeader_1x02_P2.54mm_Vertical
J13: Digital interface; IDC-Header_2x10_P2.54mm_Vertical
J14: AINN; SMA_Wurth_60312002114503_Vertical
J15: AINN; PinHeader_1x02_P2.54mm_Vertical
J16: VREF; TerminalBlock_bornier-3_P5.08mm
J17: CALIB EEPROM; PinHeader_1x04_P2.54mm_Vertical
J18: ANALOG EXT POWER; TerminalBlock_bornier-4_P5.08mm
J19: VCOM BUFF; SMA_Wurth_60312002114503_Vertical
J20: USB_C_Receptacle_PowerOnly_6P; USB_C_Receptacle_MOLEX_217175-0001_6P_TopMnt_Horizontal
J21, J23: EN; PinHeader_1x02_P2.54mm_Vertical
J22, J24: EN_DGND; PinHeader_1x02_P2.54mm_Vertical
J25: VREF2.5V; PinHeader_1x02_P2.54mm_Vertical
JP1: EEPROM WP; PinHeader_1x02_P2.54mm_Vertical
JP2: EXT<->USB|AVDD1; PinHeader_1x03_P2.54mm_Vertical
JP3: EXT<->USB|AVDD2; PinHeader_1x03_P2.54mm_Vertical
JP4: EXT<->USB|AVSS; PinHeader_1x03_P2.54mm_Vertical
Q1: MMBT3906; SOT-23
R1, R43, R46, R53, R56: 1K; R_0805_2012Metric_Pad1.20x1.40mm_HandSolder
R2, R3: 2K; R_0805_2012Metric_Pad1.20x1.40mm_HandSolder
R4, R19: 887; R_0805_2012Metric_Pad1.20x1.40mm_HandSolder
R5, R23: 20; R_0805_2012Metric_Pad1.20x1.40mm_HandSolder
R6, R24: 30R; R_0805_2012Metric_Pad1.20x1.40mm_HandSolder
R7, R8, R9, R10, R45: 10K; R_0805_2012Metric_Pad1.20x1.40mm_HandSolder
R11, R25: 147R; R_0805_2012Metric_Pad1.20x1.40mm_HandSolder
R12, R17: 249K; R_0805_2012Metric_Pad1.20x1.40mm_HandSolder
R13, R14, R15, R16, R18, R21, R22: 0R; R_0805_2012Metric_Pad1.20x1.40mm_HandSolder
R20, R26: 10R5; R_0805_2012Metric_Pad1.20x1.40mm_HandSolder
R27, R30, R31, R32, R34, R35, R36, R38, R49: 10R; R_0805_2012Metric_Pad1.20x1.40mm_HandSolder
R28, R29, R37: 0R1; R_0805_2012Metric_Pad1.20x1.40mm_HandSolder
R33: 3R; R_0805_2012Metric_Pad1.20x1.40mm_HandSolder
R39, R40: 100K; R_0805_2012Metric_Pad1.20x1.40mm_HandSolder
R41, R42: 1R; R_0805_2012Metric_Pad1.20x1.40mm_HandSolder
R44: 37R4; R_0805_2012Metric_Pad1.20x1.40mm_HandSolder
R47, R48: 5K1; R_0805_2012Metric_Pad1.20x1.40mm_HandSolder
R50: 15K; R_0805_2012Metric_Pad1.20x1.40mm_HandSolder
R51: 120R; Vishay_L7.62mm_D2.67mm_P3.81_5.08mm_Horizontal
R52: 2R; R_0805_2012Metric_Pad1.20x1.40mm_HandSolder
R54: 750; R_0805_2012Metric_Pad1.20x1.40mm_HandSolder
R55: 5.62K; R_0805_2012Metric_Pad1.20x1.40mm_HandSolder
T1: Transformer_1P_1S; CMQEE-3440A
TP1: VREFBUF; TestPoint_Keystone_5269
TP2: OUTDAC+; TestPoint_Keystone_5269
TP3: TIN+; TestPoint_Keystone_5269
TP4: TOUT+; TestPoint_Keystone_5269
TP5: TIN-; TestPoint_Keystone_5269
TP6: TOUT-; TestPoint_Keystone_5269
TP7: OUTDAC-; TestPoint_Keystone_5269
TP8: TP_START; TestPoint_Keystone_5269
TP9: TP_CLK; TestPoint_Keystone_5269
TP10: TP_DRDY; TestPoint_Keystone_5269
TP11: TP_SDO; TestPoint_Keystone_5269
TP12: TP_SCLK; TestPoint_Keystone_5269
TP13: TP_SDI; TestPoint_Keystone_5269
TP14: TP_CS; TestPoint_Keystone_5269
TP15: TP_RST; TestPoint_Keystone_5269
TP16, TP17, TP18: TP_GND; TestPoint_Keystone_5269
TP19: TP_AVSS; TestPoint_Keystone_5269
TP20: TP_AVDD1; TestPoint_Keystone_5269
TP21: TP_AVDD2; TestPoint_Keystone_5269
TP22: TP_VCOM; TestPoint_Keystone_5269
TP23: TP_IOVDD; TestPoint_Keystone_5269
TP24: TMBUF+; TestPoint_Keystone_5269
TP25: TMBUF-; TestPoint_Keystone_5269
TP26: SYNC; TestPoint_Keystone_5269
TP27: SCLK; TestPoint_Keystone_5269
TP28: SDIN; TestPoint_Keystone_5269
TP29: SDO; TestPoint_Keystone_5269
TP30: LDAC; TestPoint_Keystone_5269
TP31: CLR; TestPoint_Keystone_5269
TP32: RST; TestPoint_Keystone_5269
TP33: VCM; TestPoint_Keystone_5269
U1, U2: ADA4523-1; SOIC127P600X175-8N
U3, U4: LT6018; SOIC127P599X175-9N
U5: ADS127L11IPWT; SOP65P640X120-20N
U6: 24LC00; SOIC127P600X175-8N
U7: OPA192; SOT-23-5_HandSoldering
U8: ADA4522-4; SOIC-14_3.9x8.7mm_P1.27mm
U9: ADR1001; LCC-20
U10: LT6202; SOIC127P600X175-8N

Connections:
+3.3V: C35.1, J13.19, J17.4, JP1.1 (A), R29.2, R39.1, R40.1, TP23.1, U6.8 (VCC)
+VDC: C1.1, C2.2, C3.2, C10.2, C11.1, C12.1, C42.1, C46.2, IC1.13 (VDD), IC2.3 (VDD_1), IC2.5 (VDD_2), IC3.13 (VDD), IC4.7 (V+), IC5.7 (V+), J1.3, J21.1, J23.1, Q1.1 (B), R7.1, R8.1, R9.1, R10.1, U1.7 (V+), U2.7 (V+), U3.7 (V+), U4.7 (V+), U9.18 (HTR_IN), U9.19 (VIN), U10.7 (V+)
-VDC: C5.1, C6.2, C7.1, C8.1, C9.1, C16.2, C47.1, D2.1 (A1), IC1.5 (VSS), IC2.17 (VSS_1), IC2.18 (VSS_2), IC3.5 (VSS), IC4.4 (V-), IC5.4 (V-), J1.1, U1.4 (V-), U2.4 (V-), U3.4 (V-), U3.9 (EP), U4.4 (V-), U4.9 (EP), U10.4 (V-)
ADC+: C19.2, J8.1 (In), R6.2, TP2.1
ADC-: C19.1, J10.1 (In), R24.2, TP7.1
AINN: C28.2, C29.2, J14.1 (In), J15.2, U5.5 (AINN)
AINP: C22.1, C28.1, J11.1 (In), J12.2, U5.4 (AINP)
AVDD1: C36.1, JP2.2 (C), R37.1, TP20.1, U7.5 (V+)
AVDD2: JP3.2 (C), R28.2, TP21.1
AVSS: C22.2, C23.1, C24.1, C25.1, C26.1, C27.1, C29.1, C30.1, C36.2, C37.2, C40.2, JP4.2 (C), TP19.1, U5.20 (AVSS), U7.2 (V-)
CI_TMUXSEL1: IC3.1 (SEL1), J9.4
CI_TMUXSEL2: IC3.9 (SEL2), J9.6
CLK_DAC: R30.1, TP9.1, U5.15 (CLK)
CLR_VREF_DAC: IC2.6 (~CLR), R9.2, R21.2
CS_DAC: R36.1, R39.2, TP14.1, U5.10 (~CS)
DRDY_DAC: R31.1, TP10.1, U5.14 (~DRDY)
EXT_AVDD1: C39.1, D4.1 (K), JP2.3 (B), R42.2
EXT_AVDD2: C38.1, D3.1 (K), JP3.3 (B), R41.2
EXT_AVSS: C38.2, C39.2, D3.2 (A), D4.2 (A), J18.2, JP4.3 (B)
GND: C1.2, C2.1, C3.1, C5.2, C6.1, C7.2, C8.2, C9.2, C10.1, C11.2, C12.2, C15.1, C16.1, C31.2, C32.2, C35.2, C42.2, C43.2, C46.1, C47.2, C48.1, D1.2 (A), IC1.6 (GND), IC2.16 (VREFN), IC2.19 (AGND), IC3.6 (GND), J1.2, J4.1, J5.1, J6.1, J7.1, J8.2 (Ext), J10.2 (Ext), J11.2 (Ext), J12.1, J13.1, J13.2, J13.4, J13.6, J13.8, J13.10, J13.12, J13.14, J13.16, J13.18, J13.20, J14.2 (Ext), J15.1, J16.2, J17.1, J18.1, J19.2 (Ext), J22.2, J24.2, J25.2, Q1.3 (C), R20.2, R26.2, R47.1, R48.1, R49.2, TP16.1, TP17.1, TP18.1, U5.17 (DGND), U6.1 (A0), U6.2 (A1), U6.3 (A2), U6.4 (GND), U9.16 (HTR_GND)
GNDD: C13.2, C14.2, IC2.15 (DGND), J9.2, J9.8, J9.10, J9.12, J9.14, J9.16, J9.18, J9.20
GNDREF: R51.2, U9.8 (INV1), U9.13 (BUF_GND), U9.14 (REF_GND), U9.15 (REF_GND)
IOVCC: C13.1, C14.1, IC2.8 (VCC), IC2.9 (IOVCC), J9.1
LDAC_VREF_DAC: IC2.7 (~LDAC), R8.2, R18.2
unnamed: C17.2, C18.1, R4.2
unnamed: C20.2, C21.1, R19.2
unnamed: C23.2, C24.2, R33.1, R37.2
unnamed: C41.1, R44.2, U7.1
unnamed: C41.2, R45.1
unnamed: C45.1, R55.2
unnamed: C45.2, R52.1, U10.6
unnamed: D1.1 (K), D2.2 (K2), Q1.2 (E), R56.2
unnamed: D2.3 (K3A4), IC1.4 (S1B), IC1.10 (S2A), R1.2
unnamed: C4.1, IC2.24 (INV), U1.2 (-)
unnamed: C48.2, IC2.2 (VREFP), R52.2, R53.2, R54.1, TP1.1
unnamed: C15.2, IC3.3 (D1), IC3.11 (D2), R2.1, R3.2, TP33.1
unnamed: C18.2, IC4.3 (+)
unnamed: IC4.2 (-), R11.2, R20.1
unnamed: IC4.6, R4.1, R6.1, R11.1
unnamed: C21.2, IC5.3 (+)
unnamed: IC5.2 (-), R25.2, R26.1
unnamed: IC5.6, R19.1, R24.1, R25.1
unnamed: J2.1, J4.2, R1.1, R56.1
unnamed: J9.7, R13.1, TP26.1
unnamed: J9.9, R14.1, TP27.1
unnamed: J9.11, R15.1, TP28.1
unnamed: J9.13, R16.1, TP29.1
unnamed: J9.15, R18.1, TP30.1
unnamed: J9.17, R21.1, TP31.1
unnamed: J9.19, R22.1, TP32.1
unnamed: J13.3, R27.2
unnamed: J13.5, R30.2
unnamed: J13.7, R31.2
unnamed: J13.9, R32.2
unnamed: J13.11, R34.2
unnamed: J13.13, R35.2
unnamed: J13.15, R36.2
unnamed: J13.17, R38.2
unnamed: J18.3, R41.1
unnamed: J18.4, R42.1
unnamed: J20.A5 (CC1), R47.2
unnamed: J20.B5 (CC2), R48.2
unnamed: J21.2, U3.8 (EN)
unnamed: J22.1, U3.1 (DGND)
unnamed: J23.2, U4.8 (EN)
unnamed: J24.1, U4.1 (DGND)
unnamed: JP1.2 (B), U6.7 (WP)
unnamed: R5.2, T1.1 (AA), TP3.1
unnamed: R23.2, T1.2 (AB), TP5.1
unnamed: C20.1, R17.2, T1.3 (SA), TP6.1
unnamed: C17.1, R12.2, T1.4 (SB), TP4.1
unnamed: C44.2, R53.1, U2.2 (-)
unnamed: R33.2, U5.3 (AVDD1)
unnamed: C25.2, C26.2, R28.1, U5.2 (AVDD2)
unnamed: C27.2, U5.1 (CAPA)
unnamed: C30.2, U5.18 (CAPD)
unnamed: C31.1, C32.1, R29.1, U5.16 (IOVDD)
unnamed: C40.1, R43.1, U7.3 (+)
unnamed: R45.2, R46.2, U7.4 (-)
unnamed: U8.10 (+), U9.7 (INV2)
unnamed: U9.10 (VDOUT), U9.11 (BUF_INP)
unnamed: R49.1, U9.17 (HTR_ILIM)
unnamed: R51.1, U9.1 (ISET)
unnamed: R50.1, U9.20 (PWRGD)
unnamed: U9.4 (REF6P6_F), U9.5 (REF6P6_S), U9.6 (VDIN)
unnamed: C44.1, U2.6, U10.3 (+)
unnamed: R54.2, R55.1, U10.2 (-)
REFN: C33.2, C34.2, J16.3, U5.8 (REFN)
REFP: C33.1, C34.1, J16.1, U5.7 (REFP)
RESET_DAC: R38.1, R40.2, TP15.1, U5.9 (~RESET)
RESET_VREF_DAC: IC2.4 (~RESET), R10.2, R22.2
SCL: J17.2, U6.6 (SCL)
SCLK_DAC: R34.1, TP12.1, U5.12 (SCLK)
SCLK_VREF_DAC: IC2.13 (SCLK), R14.2
SDA: J17.3, U6.5 (SDA)
SDIN_VREF_DAC: IC2.12 (SDIN), R15.2
SDI_DAC: R35.1, TP13.1, U5.11 (SDI)
SDO_DAC: R32.1, TP11.1, U5.13 (SDO/~DRDY)
SDO_VREF_DAC: IC2.11 (SDO), R16.2
START_DAC: R27.1, TP8.1, U5.19 (START)
SYNC_VREF_DAC: IC2.14 (~SYNC), R7.2, R13.2
TMUXOUT1: IC1.3 (D1), IC3.4 (S1B), TP24.1, U3.3 (+)
TMUXOUT2: IC1.11 (D2), IC3.12 (S2B), TP25.1, U4.3 (+)
TMUXSEL1: IC1.1 (SEL1), J9.5
TMUXSEL2: IC1.9 (SEL2), J9.3
TMUX_BUF_OUT1: R2.2, R5.1, U3.2 (-), U3.6
TMUX_BUF_OUT2: R3.1, R23.1, U4.2 (-), U4.6
USB_AVDD: J20.A9 (VBUS), J20.B9 (VBUS), JP2.1 (A), JP3.1 (A)
USB_GND: J20.A12 (GND), J20.B12 (GND), J20.S1 (SHIELD), JP4.1 (A)
VCOM: R43.2, TP22.1, U5.6 (VCM)
VCOM_BUFF: C37.1, J19.1 (In), R44.1, R46.1
VRef: J3.1, J5.2, U2.3 (+)
VRef2.5V: J25.1, R12.1, R17.1, U8.8, U8.9 (-)
VRef5V: C43.1, U9.9 (BUF_S), U9.12 (BUF_F)
VRefDAC2xOut: C4.2, IC1.2 (S1A), IC1.12 (S2B), IC2.20 (RFB), U1.6
VRefDACOut: IC2.1 (VOUT), U1.3 (+)

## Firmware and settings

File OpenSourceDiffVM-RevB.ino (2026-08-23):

/*
 * SPDX-License-Identifier: CERN-OHL-P-2.0
 * SPDX-FileCopyrightText: Copyright 2025, 2026 Randall K McRee
 */

/*
  Teensy 4.x + ADS127L11 + DAC + TMUX chopped measurement

  Pin mapping:
   - Teensy SPI pins: SCK=13, MOSI=11, MISO=12 (default SPI)
   - ADC CS = Teensy pin 41
   - DAC CS = Teensy pin 10
   - TMUX_EN = Teensy pin 4
   - ADC DRDY = Teensy pin 15
   - External ADC clock = 25.0 MHz (fMOD = fCLK/2)
   - VREF = 2.500 V
   - Mux cycle around 400 Hz => 1.25 ms high, 1.25 ms low
*/

#include <Arduino.h>
#include <SPI.h>
#include <EEPROM.h>
#include <LittleFS.h>
#include "AD5760.h"
#include "CalVerify.h"
#include "OhmsMeas.h"
#include "RtsDetector.h"

// ---------------- Forward Declarations ----------------
// Types must be declared before Arduino auto-generates function prototypes
// (prototypes are inserted after the last #include, which is <limits> below)
struct HalfCycleResult;  // defined after LowerMoments
class LowerMoments;
class ScopedInstrumentState;
class InputMuxDriver;
class DividerMuxDriver;
class ChopperDriver;
class DacDriver;
class AdcDriver;
class DacCalibrationTable;
class CalibrationStore;
class IOutputFormatter;
struct MeasurementData;
struct SavedConfig;
enum class InputChannel : uint8_t;
enum class DividerRatio : uint8_t;

// ---------------- Output Verbosity Flags ----------------
// Set to true to include the drift and Allan deviation lines in human-readable output.
static constexpr bool SHOW_DRIFT = false;
static constexpr bool SHOW_ADEV  = false;

// ---------------- POST Configuration ----------------
// Set to true to halt on POST failure, false to continue with warning
static constexpr bool POST_HALT_ON_FAIL = false;

// Zero calibration test threshold (in nanovolts at input)
// With preamp gain of 2000 and ADC LSB of ~298nV, this translates to ADC counts.
// Loose bound: chain has natural ~250 µV RTI residual offset (chopping doesn't fully cancel
// every error term; observed ~248 µV on a healthy unit). Auto-zero compensates this in normal
// operation. POST threshold catches "totally broken" not "needs auto-zero".
static constexpr double POST_ZERO_THRESHOLD_NV = 500000.0;  // nV (500 µV)

// POST result structure
struct PostResult {
  bool adc_comm;
  bool dac_comm;
  bool drdy_timing;
  bool pin_id;
  bool signal_chain;
  bool polarity;
  bool chop_symmetry;
  bool input_mux;
  bool references;
  bool zero_cal;

  bool allPassed() const {
    return adc_comm && dac_comm && drdy_timing && pin_id &&
           signal_chain && polarity && chop_symmetry &&
           input_mux && references && zero_cal;
  }
};

// ---------------- Pins ----------------
static constexpr uint8_t PIN_CS_ADC     = 41;  // ADC chip select
static constexpr uint8_t PIN_CS_DAC     = 10;  // DAC chip select
static constexpr uint8_t PIN_DAC_RESET  = 25;  // DAC reset
static constexpr uint8_t PIN_DAC_CLEAR  = 24;  // DAC clear
static constexpr uint8_t PIN_ADC_DRDY   = 15;  // ADC DRDY (updated)
static constexpr uint8_t PIN_ADC_START  = 17;  // ADC START (LOW = idle)
static constexpr uint8_t PIN_ADC_RESET  = 40;  // ADC RESET (active low; HIGH = running)
static constexpr uint8_t PIN_CLK_ADC    = 9;   // ADC clock
static constexpr uint8_t PIN_TMUX_EN    = 4;   // TMUX enable
static constexpr uint8_t PIN_TMUXSEL    = 2;   // Controls the main DAC/Vx switches (Switches A and B)
static constexpr uint8_t PIN_CI_TMUXSEL = 3;   // Controls the common-mode voltage switches (Switches C and D)

// Input multiplexer (MUX36S08) - selects between Vx, GND, VrefRaw, ranges
static constexpr uint8_t PIN_INMUX_A0   = 35;  // Input mux address bit 0
static constexpr uint8_t PIN_INMUX_A1   = 34;  // Input mux address bit 1
static constexpr uint8_t PIN_INMUX_A2   = 33;  // Input mux address bit 2
// MUX36D08 EN hardwired to VDD (active high, always enabled) - no GPIO needed

// HV Divider tap select (MUX36D04 dual 4:1 mux, EN hardwired ON)
static constexpr uint8_t PIN_DIVMUX_A0  = 23;  // MUX36D04 A0: divider tap address bit 0
static constexpr uint8_t PIN_DIVMUX_A1  = 22;  // MUX36D04 A1: divider tap address bit 1

// Ohms-mode breakout (OHMS-1 errata — external breakout, ribbon to Teensy).
// R_ref selection is now manual (resistor physically wired into the socket);
// firmware only controls excitation polarity and magnitude. The `rref` CLI
// tells the firmware which resistor is currently installed.
static constexpr uint8_t PIN_OHMS_POL     = 5;  // SW1 (TMUX7234) polarity: LOW = +V_exc, HIGH = -V_exc (as-built; NO/NC swapped vs schematic)
static constexpr uint8_t PIN_OHMS_EXC_LOW = 21; // V_exc magnitude: HIGH = 1 V, LOW = 2.5 V (default)
// Pins 6, 7, 8 are now FREE (previously R_ref MUX A0/A1/A2 — mux removed).

// ---------------- Timing ----------------
// Nominal at F_CPU=600 MHz; updated at runtime by calibrateAdcClock() from a
// measured DRDY period. Required because analogWriteFrequency() on PIN_CLK_ADC
// derives from a FlexPWM peripheral clock that scales with F_CPU and snaps to
// integer dividers — e.g. a request for 25 MHz lands on ~17.6 MHz at F_CPU=528.
static float              ADC_FCLK_HZ       = 25'000'000.0f;   // external clock (nominal)
static float              ADC_FMOD_HZ       = 12'500'000.0f;   // fMOD = fCLK/2 (nominal)
static constexpr uint32_t SETTLE_US         = 600;             // generic post-event guard (mux changes, POST tests)
static constexpr uint32_t CHOP_SETTLE_US    = 2000;            // post-chop-edge settle: preamp + TMUX + AAF. 2000 µs for 47nF CI cap (was 800 µs at 21nF, 10000 µs was too slow — pushed fchop to 24 Hz, below 60 Hz line noise alias)
static uint8_t            g_discard_samples = 1;               // ADC outputs discarded per half-cycle for filter flush; runtime-configurable via "discard N"
static constexpr uint8_t  MAX_SAMPLES       = 27;              // max ADC readings per each chop phase
static constexpr int      CI_PRE_EDGE_US    = 50;              // CI cancel switches HIGH before TMUXSEL flip
static constexpr int      CI_POST_EDGE_US   = 100;             // CI cancel switches HIGH after TMUXSEL flip
uint8_t                   g_good_samples    = 14;              // samples to average per half-cycle; runtime-tunable via `samples N`

// ---------------- Demodulation Outlier Rejection (Pooled-MAD) ----------------
// Pair-diffs from the last DEMOD_POOL_N cycles are kept in a ring buffer.
// Each demodulate() call: push this cycle's diffs, recompute pooled median +
// MAD, threshold = max(k·1.4826·MAD, FLOOR). Pooling stabilises the threshold
// across cycles so the rejection bias is a constant offset (cancels in (A-B)/2)
// instead of a wandering one (which injects flicker at long ADEV τ).
// Runtime-tunable via 'drj <k>' command. k=10000 effectively disables rejection.
static int32_t           g_demodRejKx10    = 80;    // k = 8.0  (×10 for integer math)
static constexpr int32_t DEMOD_REJ_FLOOR  = 32;     // ADC counts, floor for pooled-MAD rejection threshold
static constexpr int     DEMOD_POOL_N      = 256;   // pair-diff ring buffer depth
static constexpr int     DEMOD_POOL_MIN    = 64;    // skip rejection until this many entries collected
static int32_t           g_diffPool[DEMOD_POOL_N];
static int               g_diffPoolHead    = 0;
static int               g_diffPoolFilled  = 0;

// Flush pool history. MUST be called whenever the signal level steps abruptly
// (DAC change, channel switch, range change) — otherwise the lagging pool
// median biases the next ~DEMOD_POOL_N pair-diffs toward the previous level.
static inline void demodPoolReset() {
  g_diffPoolHead = 0;
  g_diffPoolFilled = 0;
}
static uint64_t          g_demodRejTotal   = 0;
static uint64_t          g_demodPairsTotal = 0;
static uint32_t          g_demodRejSinceOutput   = 0;
static uint32_t          g_demodPairsSinceOutput = 0;
// Last pooled-MAD stats from demodulate(), for the `drj` CLI: lets the user
// see whether the k·1.4826·MAD term or DEMOD_REJ_FLOOR is the operative
// threshold (at high OSR the per-sample MAD can shrink until the floor
// silently takes over and the effective k is much tighter than the set k).
static int32_t           g_lastDemodMed       = 0;
static int32_t           g_lastDemodMad       = 0;
static int32_t           g_lastDemodThreshold = 0;   // post-floor; only valid once pool ready (CLI checks)

// ---------------- DAC Filter Settling ----------------
// Second-order Bessel filter on DAC output requires settling after step changes.
// From measured step response:
//   - Overshoot peak: ~0.45% at t≈107ms
//   - Undershoot trough: ~0.002% at t≈220ms
//   - 10 ppm settling: t≈250ms for full-scale step
// Settling time scales with sqrt(step_size) for constant absolute error.
static constexpr uint32_t DAC_SETTLE_MIN_MS = 80;   // Minimum settling (small steps, ~1% relative)
static constexpr uint32_t DAC_SETTLE_MAX_MS = 300;  // Maximum settling (full-scale, ~10 ppm relative)

// ---------------- Input Mux Configuration ----------------
// MUX36S08 settling time: ~100ns switching + signal path settling
// Use conservative settling for precision measurements
static constexpr uint32_t INMUX_SETTLE_US = 100;  // Input mux settling time (µs)

// Input channel enumeration (directly maps to MUX36S08 address lines)
enum class InputChannel : uint8_t {
  Vx1     = 0,  // S1: Unknown input 1 (normal measurement, ±5V)
  GND     = 1,  // S2: Ground reference (zero calibration)
  VrefRaw = 2,  // S3: Raw (pre-filter) ADR1001 average (J3) for drift compensation
  Vx2     = 3,  // S4: Unknown input 2
  Vx3     = 4,  // S5: Unknown input 3
  HVDiv   = 5,  // S6: HV divider output (ratio selected by MUX36D04)
  Vx4     = 6,  // S7: Unknown input 4
  Vx5     = 7,  // S8: Unknown input 5
};

// ---------------- HV Divider Ratio Selection (MUX36D04) ----------------
// Caddock 1776-C4815 serial-parallel arrangement with MUX36D04 tap selection
// The 1:10 divider is hardwired always in circuit for safety (no HV transients).
// MUX switches parallel resistances to change ratio; address 3 connects to GND.
enum class DividerRatio : uint8_t {
  Div10   = 0,  // Mux bypassed: 1:10 ratio only (hardwired), ±50V range
  Div100  = 1,  // CD4-AB4 bridged: 100k arm || 1M, ±500V range
  Div1000 = 2,  // CD5-AB5 bridged: 10k arm || 1M, ±5000V range
  GND     = 3,  // Ground connection for zero calibration
};

// ---------------- Voltage Divider Ratios ----------------
// Calculated ratios for Caddock 1776-C4815 serial-parallel divider
// Segments: 10M, 1.1111M, 101.01K, 10.01K (4 dividers as 2 parallel pairs in series)
// MUX path = Rseg/2 + Rseg/2 + 250Ω; base 1M arm = 1.1111M (always in circuit)
// Runtime-mutable for in-situ calibration; defaults match calculated values.
// Use 'cal set div10/div100/div1000 <v>' to adjust; 'cal factory' to reset.
static constexpr double DIVIDER_RATIO_10_DEFAULT   = 10.0;
static constexpr double DIVIDER_RATIO_100_DEFAULT  = 108.76;
static constexpr double DIVIDER_RATIO_1000_DEFAULT = 984.65;
static double DIVIDER_RATIO_10   = DIVIDER_RATIO_10_DEFAULT;    // ±50V: mux bypassed
static double DIVIDER_RATIO_100  = DIVIDER_RATIO_100_DEFAULT;   // ±500V: 1.1111M || 101.26K
static double DIVIDER_RATIO_1000 = DIVIDER_RATIO_1000_DEFAULT;  // ±5kV: 1.1111M || 10.26K

// ---------------- Precision Voltage Constants (64-bit double) ----------------
// ADC: ADS127L11, 24-bit, differential, VREF = 2.500V nominal.
// The VREF pin is driven through a 100Ω series resistor (added to handle capacitive load),
// which introduces a small voltage drop proportional to reference input current.
// Measure the actual voltage at the ADS127L11 VREF pin with a precision meter and
// set it with 'cal set adcvref <V>' to remove this scale error.
static constexpr double ADC_VREF_DEFAULT = 2.500;
static double ADC_VREF     = ADC_VREF_DEFAULT;       // runtime-calibratable; use 'cal set adcvref'
static constexpr double ADC_FSR_CODES   = 16777216.0; // 2^24 full scale codes
static double ADC_LSB_V    = (2.0 * ADC_VREF_DEFAULT) / ADC_FSR_CODES;  // updated when ADC_VREF changes

// ---------------- Overflow Detection ----------------
// 24-bit ADC full scale: ±8,388,607. Use 95% threshold for overflow detection.
static constexpr int32_t ADC_OVERFLOW_POS   =  0.95 * ADC_FSR_CODES/2;      // ~95% of 0x7FFFFF
static constexpr int32_t ADC_OVERFLOW_NEG   = -1.00 * ADC_OVERFLOW_POS;     // ~95% of -0x800000

// DAC: AD5760, 16-bit, two's complement in 2x mode, VREFP=5V, VREFN=0V
// Output range: ±5V (with 2x gain), codes 0x8000 (-32768) to 0x7FFF (+32767)
static constexpr double DAC_VREF        = 5.0;                           // DAC full-scale voltage (V)
static constexpr double DAC_FSR_CODES   = 65536.0;                       // 2^16 codes
static constexpr double DAC_LSB_V       = (2.0 * DAC_VREF) / DAC_FSR_CODES;  // ~152.6 µV/LSB

// Preamp: 4× AD8428 (or INA848) in parallel, total gain = 2000
// Runtime-mutable for in-situ calibration. Use 'cal set gain <v>' to adjust.
static constexpr double PREAMP_GAIN_DEFAULT = 2000.0;
static double PREAMP_GAIN = PREAMP_GAIN_DEFAULT;

// Cache for 'cal gain' — updated by outputMeasurement each cycle.
// g_calLastVoltage is ewmaV when EWMA is initialized, else vxCorrected — the same
// value the user sees as the primary reading.
static double       g_calLastVoltage = NAN;
static int16_t      g_calLastDacCode = 0;
static InputChannel g_calLastChannel = InputChannel::Vx1;

// OPA828 buffer offset at the HV divider output node (volts, measured at buffer output).
// Chopping does NOT cancel this offset — it must be calibrated out explicitly.
// Apply with 'cal set opa828 <v>' after measuring with DAC tracking at GND divider output.
static constexpr double OPA828_OFFSET_DEFAULT = 0.0;
static double OPA828_OFFSET = OPA828_OFFSET_DEFAULT;
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
void loop() {
  // Process serial commands
  processSerialCommands();

  if (g_refTrackEnabled && (++refSampleCounter >= REF_SAMPLE_INTERVAL)) {
    refSampleCounter = 0;
    measureFilterError();
  }

  // ---- ONE_CHANNEL MODE: measure current channel continuously ----
  if (scanner.isOneChannel()) {
    InputChannel curCh = inputMux.current();

    // Clear stats and reset integration counter whenever the channel changes
    // (covers range switches, ScopedInstrumentState restore, first entry after scan stop)
    static InputChannel lastOneChannel = static_cast<InputChannel>(0xFF);
    static int loopCounter = 0;
    if (curCh != lastOneChannel) {
      scanner.channelStats((uint8_t)curCh).clear();
      g_rts.reset();                               // RTS detector history is per-channel
      loopCounter = 0;
      lastOneChannel = curCh;
    }

    LowerMoments &stats = scanner.channelStats((uint8_t)curCh);
	  int32_t* bA = scanner.bufferA((uint8_t)curCh);
	  int32_t* bB = scanner.bufferB((uint8_t)curCh);

    // Snapshot for per-cycle pair-diff extraction (RTS detector input).
    const double rtsN0 = stats.count();
    const double rtsM0 = (rtsN0 > 0.0) ? stats.mean() : 0.0;

    if (!runOneChopCycle(stats, bA, bB)) {
      scanner.resetChannelEwma((uint8_t)curCh);  // DAC re-centered: old EWMA history is stale
      g_rts.reset();                              // chop state cleared → detector state is stale
      loopCounter = 0;
      return;  // Overflow handled, restart
    }

    // Extract this cycle's pair-diff mean from the LowerMoments delta and feed
    // it to the RTS detector. Cheap: zero work when disabled.
    if (g_rts.enabled()) {
      const double rtsN1 = stats.count();
      const double dn    = rtsN1 - rtsN0;
      if (dn > 0.0) {
        const double dsum = rtsN1 * stats.mean() - rtsN0 * rtsM0;
        const double perCycleAdc = dsum / dn;
        const double vxCycle = computeInputVoltage(perCycleAdc, dac.currentCode(), curCh);
        RtsDetector::Event ev;
        if (g_rts.process(vxCycle, &ev)) {
          Serial.print(F("** RTS #")); Serial.print(g_rts.eventCount());
          Serial.print(F(" @cycle ")); Serial.print(ev.sampleIdx);
          Serial.print(F(": dV = "));  Serial.print(ev.magnitude * 1e9, 3);
          Serial.println(F(" nV"));
        }
      }
    }

    // Output every integrationCycles, then clear for fixed-window integration
    if (++loopCounter >= scanner.config.integrationCycles) {
      loopCounter = 0;
      outputMeasurement(curCh, stats, dac.currentCode());
      stats.clear();

      // Auto-zero: same interval logic as SCANNING mode (counts readings, not sweeps)
      scanner.incCycleCount();
      if (scanner.config.autoZeroEnabled &&
          (scanner.cycleCount() % scanner.config.autoZeroInterval) == 0) {
        performAutoZero();
        if (scanner.autoZeroValid && scanner.config.outputMode == OutputMode::Human) {
          Serial.print("  [auto-zero: offset=");
          Serial.print(scanner.autoZeroOffset * 1e9, 1);
          Serial.print(" nV  sdev=");
          Serial.print(scanner.autoZeroSdev * 1e9, 1);
          Serial.println(" nV]");
        }
      }
    }
    return;
  }

  // ---- SCANNING MODE ----
  InputChannel scanCh = scanner.config.channels[scanner.currentScanIndex()];

  // Run one chop cycle on the current channel
  LowerMoments &stats = scanner.channelStats((uint8_t)scanCh);
  int32_t* bA = scanner.bufferA((uint8_t)scanCh);
  int32_t* bB = scanner.bufferB((uint8_t)scanCh);
  if (!runOneChopCycle(stats, bA, bB)) {
    scanner.setChopCycleCount(0);  // Reset after overflow/DAC change
    scanner.setChannelDac((uint8_t)scanCh, dac.currentCode());
    scanner.resetChannelEwma((uint8_t)scanCh);  // DAC re-centered: old EWMA history is stale
    return;
  }

  scanner.incChopCycleCount();

  // Discard initial settling cycles after channel switch
  if (scanner.chopCycleCount() <= SCAN_SETTLE_CYCLES) {
    stats.clear();
    return;
  }

  // Check if integration is complete for this channel
  if (scanner.chopCycleCount() >= scanner.config.integrationCycles + SCAN_SETTLE_CYCLES) {
    // Output this channel's result
    // For multi-channel plotter mode, we buffer all channels and print one line per sweep
    if (scanner.config.outputMode == OutputMode::Plotter && scanner.config.count > 1) {
      // Multi-channel plotter: assemble one tab-separated line per sweep
      double adcMean = stats.mean();
      double adcStdDev = stats.standardDeviation();
      double vxRaw = computeInputVoltage(adcMean, dac.currentCode(), scanCh);
      double refCorrection = (scanCh == InputChannel::VrefRaw) ? 1.0 : getRefCorrectionFactor();
      double vxCorrected = vxRaw * refCorrection;
      if (scanner.autoZeroValid) vxCorrected -= scanner.autoZeroOffset;
      double vxUncertainty = computeInputUncertainty(adcStdDev, scanCh);
      double driftPpb = (refCorrection - 1.0) * 1e9;

      AdjustedEWMA& ewma = scanner.channelEwma((uint8_t)scanCh);
      double ewmaV = ewma.update(vxCorrected);
      MeasurementData data;
      data.channel = scanCh; data.voltage = vxCorrected; data.uncertainty = vxUncertainty;
      data.adcMean = adcMean; data.adcStdDev = adcStdDev; data.count = stats.count();
      data.dacCode = dac.currentCode(); data.driftPpb = driftPpb;
      data.adcMin = stats.getMin(); data.adcMax = stats.getMax();
      data.ewmaVoltage = ewmaV; data.ewmaValid = ewma.isInitialized();

      IOutputFormatter& fmt = getFormatter();
      if (scanner.currentScanIndex() == 0) fmt.beginSweep();
      fmt.formatMeasurement(data);
      if (scanner.currentScanIndex() == scanner.config.count - 1) {
        fmt.endSweep();
        // Demod outlier-rejection report (once per sweep, comment-prefixed so plotters skip it).
        if (g_demodRejSinceOutput > 0) {
          Serial.print("# demod-clip: ");
          Serial.print(g_demodRejSinceOutput); Serial.print('/');
          Serial.print(g_demodPairsSinceOutput);
          Serial.print(" since last output (cum ");
          Serial.print((unsigned long)g_demodRejTotal); Serial.print('/');
          Serial.print((unsigned long)g_demodPairsTotal);
          Serial.println(")");
        }
        g_demodRejSinceOutput   = 0;
        g_demodPairsSinceOutput = 0;
      }
    } else {
      outputMeasurement(scanCh, stats, dac.currentCode());
    }

    // Save DAC code for this channel (for fast restore on next visit)
    scanner.setChannelDac((uint8_t)scanCh, dac.currentCode());

    // Advance to next channel
    scanner.setCurrentScanIndex(scanner.currentScanIndex() + 1);

    if (scanner.currentScanIndex() >= scanner.config.count) {
      // Completed one full sweep
      scanner.setCurrentScanIndex(0);
      scanner.incCycleCount();

      // Check if auto-zero is due
      if (scanner.config.autoZeroEnabled &&
          (scanner.cycleCount() % scanner.config.autoZeroInterval) == 0) {
        performAutoZero();
        if (scanner.autoZeroValid && scanner.config.outputMode == OutputMode::Human) {
          Serial.print("  [auto-zero: offset=");
          Serial.print(scanner.autoZeroOffset * 1e9, 1);
          Serial.print(" nV  sdev=");
          Serial.print(scanner.autoZeroSdev * 1e9, 1);
          Serial.println(" nV]");
        }
      }
    }

    // Switch to next channel
    InputChannel nextCh = scanner.config.channels[scanner.currentScanIndex()];
    if (nextCh != inputMux.current()) {
      inputMux.select(nextCh);
      uint8_t idx = (uint8_t)nextCh;
      if (scanner.channelDacValid(idx)) {
        // Restore saved DAC code (fast path: only filter settling, no search)
        dac.setCode(scanner.channelDacCode(idx));
      } else {
        // First visit to this channel: full binary search
        binarySearchDAC();
        scanner.setChannelDac(idx, dac.currentCode());
      }
    }
    scanner.channelStats((uint8_t)nextCh).clear();
    scanner.setChopCycleCount(0);
  }
}

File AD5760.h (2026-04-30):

#ifndef AD5760_H
#define AD5760_H

#include <Arduino.h>
#include <SPI.h>

class AD5760 {
private:
  // Register addresses
  static constexpr uint8_t REG_NOP       = 0x0;
  static constexpr uint8_t REG_DAC       = 0x1;
  static constexpr uint8_t REG_CTRL      = 0x2;
  static constexpr uint8_t REG_CLEARCODE = 0x3;
  static constexpr uint8_t REG_SWCTRL    = 0x4;

  // Control register low bits
  static constexpr uint16_t CTRL_RBUF    = (1u << 1);
  static constexpr uint16_t CTRL_OPGND   = (1u << 2);
  static constexpr uint16_t CTRL_DACTRI  = (1u << 3);
  static constexpr uint16_t CTRL_BIN_2SC = (1u << 4);
  static constexpr uint16_t CTRL_SDODIS  = (1u << 5);

  // Software control bits
  static constexpr uint8_t SW_LDAC  = (1u << 0);
  static constexpr uint8_t SW_CLR   = (1u << 1);
  static constexpr uint8_t SW_RESET = (1u << 2);

  uint8_t _csPin;
  uint8_t _clrPin;
  uint8_t _resetPin;

  SPIClass &_spi;
  SPISettings _spiSettings;

  float _vrefp;
  float _vrefn;

  bool    _bitbang = false;
  bool    _bitbangShared = false;  // if true, switch pins to GPIO per-transfer then restore to LPSPI4
  uint8_t _mosiPin = 0;
  uint8_t _misoPin = 0;
  uint8_t _sckPin  = 0;
public:
  // Constructor
  // csPin   = SYNC pin on AD5760
  // no ldacPin, held low
  // clrPin  = CLR pin on AD5760
  // resetPin= RESET pin on AD5760
  // spi     = SPI bus to use (default SPI)
  AD5760(uint8_t csPin,
         uint8_t clrPin,
         uint8_t resetPin,
         SPIClass &spi = SPI)
    : _csPin(csPin),
      _clrPin(clrPin),
      _resetPin(resetPin),
      _spi(spi),
      _spiSettings(1000000, MSBFIRST, SPI_MODE1),
      _vrefp(5.0f),
      _vrefn(0.0f)  {  }

  // Switch to bit-bang mode: bypasses hardware SPI entirely, uses plain GPIO on
  // the same physical pins. Call after begin(). Useful when the SPI peripheral
  // is suspected damaged. MODE1: SCK idles LOW, MOSI set during HIGH phase,
  // slave (AD5760) samples MOSI on falling edge, drives MISO after rising edge.
  void enableBitbang(uint8_t mosiPin, uint8_t misoPin, uint8_t sckPin) {
    _bitbang = true;
    _mosiPin = mosiPin;
    _misoPin = misoPin;
    _sckPin  = sckPin;
    pinMode(_mosiPin, OUTPUT);
    pinMode(_misoPin, INPUT);
    pinMode(_sckPin,  OUTPUT);
    digitalWrite(_mosiPin, LOW);
    digitalWrite(_sckPin,  LOW);  // SCK idles LOW for MODE1
  }

  // Like enableBitbang() but for a shared SPI bus (e.g. shared with an ADC).
  // Pins stay in their normal LPSPI4 (ALT3) mux function between transfers.
  // On each transfer the driver switches them to GPIO, bit-bangs, then restores
  // them to LPSPI4 so the other device is unaffected.
  // Call after begin(). Pins mosiPin/misoPin/sckPin must be the hardware SPI pins.
  void enableBitbangShared(uint8_t mosiPin, uint8_t misoPin, uint8_t sckPin) {
    _bitbang       = true;
    _bitbangShared = true;
    _mosiPin = mosiPin;
    _misoPin = misoPin;
    _sckPin  = sckPin;
    // Pins remain in LPSPI4 (ALT3) mux mode until needed
  }

  // Call once from setup().
  // spiClockHz can be much higher, but 1 MHz is a conservative starting point.
  void begin(uint32_t spiClockHz = 1000000, float vrefp = 5.0f, float vrefn = 0.0f) {
    _vrefp = vrefp;
    _vrefn = vrefn;
    _spiSettings = SPISettings(spiClockHz, MSBFIRST, SPI_MODE1);

    pinMode(_csPin, OUTPUT);
    pinMode(_clrPin, OUTPUT);
    pinMode(_resetPin, OUTPUT);

    digitalWrite(_csPin, HIGH);     // SYNC inactive high
    digitalWrite(_clrPin, HIGH);    // inactive high
    digitalWrite(_resetPin, HIGH);  // inactive high

    _spi.begin();
  }

  // Hardware reset pulse.
  void hardwareReset() {
    digitalWrite(_resetPin, LOW);
    delayMicroseconds(1);
    digitalWrite(_resetPin, HIGH);
    delayMicroseconds(10);
  }

  // RBUF=0, BIN_2SC=0: gain-of-two mode, two's complement. Requires external op-amp on VOUT.
  void configureGain2TwosComplement(bool disableSDO = false) {
    uint16_t ctrl = 0;
    if (disableSDO) ctrl |= CTRL_SDODIS;
    writeControlRegister(ctrl);
  }

  // RBUF=1, BIN_2SC=0: unity-gain mode, two's complement. Internal buffer drives VOUT directly.
  // Output spans 0V to VREFP (unipolar). No external op-amp needed. Good for initial bring-up.
  void configureUnityGainTwosComplement(bool disableSDO = false) {
    uint16_t ctrl = CTRL_RBUF;
    if (disableSDO) ctrl |= CTRL_SDODIS;
    writeControlRegister(ctrl);
  }

  // Write raw signed 16-bit two's-complement DAC code.
  void writeCode(int16_t code) {
    writeRegister16(REG_DAC, static_cast<uint16_t>(code));
  }

  // Trigger software LDAC.
  void softwareLDAC() {
    writeSoftwareControl(SW_LDAC);
  }

  // Write code, then update output using software LDAC.
  void writeCodeAndUpdate(int16_t code) {
    writeCode(code);
    //softwareLDAC(); LDAC pin tied low
  }

  // Set clearcode register.
  void setClearCode(int16_t code) {
    writeRegister16(REG_CLEARCODE, static_cast<uint16_t>(code));
  }

  // Software clear and software reset.
  void softwareClear() {
    writeSoftwareControl(SW_CLR);
  }

  void softwareReset() {
    writeSoftwareControl(SW_RESET);
  }

  // Convert desired output voltage to signed 16-bit code for gain-of-two mode.
  // General gain-of-two span:
  //   Vout_min = 2*VREFN - VREFP
  //   Vout_max = VREFP
  //
  // Common case with VREFN = 0, VREFP = 5V:
  //   Vout span ~ -5V to +5V
  int16_t voltageToCode(float volts) const {
    const float span = _vrefp - _vrefn;
    const float minV = 2.0f * _vrefn - _vrefp;
    const float maxV = _vrefp;

    float v = volts;
    if (v < minV) v = minV;
    if (v > maxV) v = maxV;

    float codeF = ((v - _vrefn) / span) * 32768.0f;

    if (codeF > 32767.0f)  codeF = 32767.0f;
    if (codeF < -32768.0f) codeF = -32768.0f;

    return static_cast<int16_t>(lroundf(codeF));
  }

  void setVoltageAndUpdate(float volts) {
    int16_t code = voltageToCode(volts);
    writeCodeAndUpdate(code);
  }


  void writeControlRegister(uint16_t ctrl) {
    writeFrame(0, REG_CTRL, static_cast<uint32_t>(ctrl) & 0xFFFFF);
  }

  void writeSoftwareControl(uint8_t sw) {
    writeFrame(0, REG_SWCTRL, static_cast<uint32_t>(sw) & 0x7);
  }

  // For DAC and clearcode registers, the 16-bit value goes into DB19..DB4.
  void writeRegister16(uint8_t reg, uint16_t value) {
    uint32_t data20 = static_cast<uint32_t>(value) << 4;
    writeFrame(0, reg, data20);
  }

  // --- Bit-bang helper ---
  // Transfer one byte, MODE1: MOSI driven before rising SCK, MISO sampled
  // during high phase (slave drives after rising edge per AD5760 t19).
  // ~100 kHz (5 µs half-period).
  uint8_t bbXfer(uint8_t out) {
    uint8_t in = 0;
    for (int i = 7; i >= 0; i--) {
      digitalWrite(_mosiPin, (out >> i) & 1);
      digitalWrite(_sckPin, HIGH);
      delayMicroseconds(5);
      in = (in << 1) | digitalRead(_misoPin);
      digitalWrite(_sckPin, LOW);
      delayMicroseconds(5);
    }
    return in;
  }
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

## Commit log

2026-02-14 Initial commit: DiffVM firmware with UI, scanning, and PC companion
    Firmware (OpenSourceDiffVM-RevB.ino):
    - Serial command interface (scan, log, plot, integrate, autozero, range, config, etc.)
    - Channel scanning state machine with per-channel statistics
    - CSV and Arduino Serial Plotter output modes
    - Auto-zero offset calibration via GND channel
    - EEPROM configuration persistence with CRC16 validation
    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
    [DAC.kicad_sch, DiffVM.kicad_pcb, DiffVM.kicad_sch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]
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2026-02-15 Add per-channel DAC code caching and Java simulation
    Cache the DAC code for each scan channel so subsequent sweeps restore
    the saved code (~80-300ms settle) instead of running a full binary
    search (~4.5s) on every channel switch. Overflow detection still
    triggers a fresh search when inputs change.
    Add Java simulation of all firmware algorithms (65 tests passing):
    LowerMoments, DAC calibration, chopping/demodulation, binary search,
    reference drift compensation, auto-zero, and full integration test.
    [AutoZero.java, BinarySearchDAC.java, BinarySearchDACTest.java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]
2026-02-15 Add Overlapping Allan Deviation (OADEV) statistics across all three codebases
    Implements real-time and batch OADEV computation for voltage stability analysis
    at octave-spaced averaging times, enabling characterization of noise types
    (white, flicker, random walk) in the DiffVM measurement chain.
    Firmware: AllanDeviation class with 4096-sample circular buffer (32 KB),
    `adev` serial command, inline ADEV summary in Human output mode, and
    lifecycle integration (cleared on scan start and factory reset).
    Java: AllanDeviation batch computation class with prefix-sum optimization,
    8 unit tests (white noise slope, known sequences, edge cases), and
    computeAllanDeviation() convenience method on DiffVMS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
    [Constants.java, DiffVMSimulator.java, OpenSourceDiffVM-RevB.ino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]
2026-02-18 Refactor firmware into encapsulated classes and fix behavioral issues
    Five-step refactoring:
    1. RAII ScopedInstrumentState for automatic channel/DAC save-restore
    2. Hardware driver classes (InputMuxDriver, DividerMuxDriver, ChopperDriver,
    DacDriver, AdcDriver) encapsulating GPIO/SPI behind clean interfaces
    3. DacCalibrationTable class encapsulating 16384-point lookup table
    4. ScanController class encapsulating scan state machine and per-channel state
    5. IOutputFormatter strategy pattern (HumanFormatter, CsvFormatter,
    PlotterFormatter) eliminating 100-line switch in outputMeasurement()
    Bug fixes and improvements:
    - Fix IDLE mode stats never clearing (now uses fixed-window integration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
    [OpenSourceDiffVM-RevB.ino]
2026-02-19 Add LittleFS flash persistence for DAC cal table, preamp gain, and divider ratios
    Implements CalibrationStore class backed by a 512 KB LittleFS_Program
    partition on the Teensy 4.1 QSPI flash. Persists two files:
    /cal_consts.bin - PREAMP_GAIN + three DIVIDER_RATIO_* values (CRC16)
    /dac_table.bin - 16384-point DAC calibration table (streamed, CRC16)
    Both files are loaded automatically at boot; cal constants are validated
    against sanity bounds before being applied.
    PREAMP_GAIN and DIVIDER_RATIO_{10,100,1000} are converted from constexpr
    to runtime-mutable static doubles (with _DEFAULT companions for factory
    reset), so they can be adjusted in-situ without recompiling.
    New 'cal' serial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
    [OpenSourceDiffVM-RevB.ino]
2026-02-19 Add DAC calibration table build procedure (CAL-02)
    Implements two new firmware commands for populating the 16,384-point
    DAC INL correction table:
    - 'cal build dac': auto-calibrates at GND and VrefRaw anchors (~10
    entries near 0 V and 5 V); marks table valid and saves to flash.
    Requires no external source; corrects zero offset and full-scale gain.
    - 'cal point <voltage>': captures one table entry from a user-supplied
    known voltage applied to Vx. Binary-searches DAC to lock onto the
    applied voltage, accumulates 20 chopped measurements, and stores
    V_dac = V_known - ADC_residual/PREAMP_GAIN at the current DAC code.
    Enables full INL correction with an external calibrated source or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
    [OpenSourceDiffVM-RevB.ino]
2026-02-20 Add POST LED blink, fix comment wording, add Teensy pin mapping spreadsheet
    - Blink LED_BUILTIN on POST failure halt (1.5s on / 1s off cycle)
    - Add pinMode(LED_BUILTIN, OUTPUT) before blink loop
    - Minor comment tweaks in setup() and header
    - Add Teensy-pin-mapping-Diff-VM-revB.xlsx hardware reference
    [Teensy-pin-mapping-Diff-VM-revB.xlsx]
2026-02-21 Run auto-zero in ONE_CHANNEL mode at the configured interval
    Previously performAutoZero() was only called from the SCANNING branch
    (after each full channel sweep). In ONE_CHANNEL mode the auto-zero
    never fired even when autozero was enabled.
    Fix: after each reading output in ONE_CHANNEL mode, increment
    scanCycleCount and trigger performAutoZero() on the same
    autoZeroInterval cadence used by SCANNING mode.
    [OpenSourceDiffVM-RevB.ino]
2026-02-21 Refactor chop loops to reuse runOneChopCycle(stats, searchOnOverflow)
    Add bool searchOnOverflow parameter (default true) to runOneChopCycle():
    - true → on overflow: binarySearchDAC() + stats.clear() (loop() behavior)
    - false → on overflow: return false immediately, caller handles it
    (correct for calibration routines that own their DAC state)
    Replace inline acquire/toggle/demodulate loops in:
    - performAutoZero() — 20-cycle GND measurement
    - measureFilterError() — REF_MEASURE_ITERATIONS reference measurement
    - cmdCalBuildDac() — both GND and VrefRaw anchor sweeps
    - cmdCalPoint() — single-point capture
    Add forward declaration for runOneChopCycle() so callers defin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
    [OpenSourceDiffVM-RevB.ino]
2026-02-21 Add AUTOZERO_CYCLES constant; refactor postTestZero() chop loop
    - Add AUTOZERO_CYCLES = 20 constant (separate from CAL_POINT_CYCLES)
    and use it in performAutoZero() instead of reusing the cal constant
    - Refactor postTestZero() inline acquire/toggle/demodulate loop to
    use runOneChopCycle(zeroStats, false), matching the pattern used
    by performAutoZero() and the calibration routines
2026-02-21 Remove global chopStats; use scanner.channelStats() in ONE_CHANNEL mode
    The global LowerMoments chopStats was a leak-prone singleton that could
    silently accumulate stale data across channel changes or mode switches.
    Replace with scanner.channelStats((uint8_t)curCh) — the same per-channel
    accumulator already used by SCANNING mode — so both modes share a single,
    consistent store keyed by channel enum.
    In the ONE_CHANNEL loop, track lastOneChannel (initialised to 0xFF sentinel)
    and clear stats + reset loopCounter whenever inputMux.current() changes.
    This handles range switches, ScopedInstrumentState restores (auto-zero,
    cal commands), and the first entry after scan stop without any extra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
    [OpenSourceDiffVM-RevB.ino]
2026-02-21 Add getInputDividerRatio() forward decl; rename scanCycleCount -> cycleCount
    - Forward-declare getInputDividerRatio(InputChannel) immediately before the
    Precision Voltage Computation section, after InputChannel and
    DacCalibrationTable are defined — the one spot where it is both visible
    to its callers (computeInputVoltage/Uncertainty) and has access to the
    InputChannel type.
    - Rename ScanController members and accessors:
    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
2026-02-21 Fix auto-zero interval wording: "scan sweeps" -> "cycles"
    User-visible strings in cmdAutoZeroInterval(), printStatus(), and
    printHelp() still said "scan sweeps" after cycleCount_ was made
    mode-neutral. Replace with "cycles" throughout, and expand the help
    line to clarify the semantics per mode:
    "Cycles between auto-zero (readings in ONE_CHANNEL, sweeps in SCANNING)"
    Internal code comments and the beginSweep/endSweep method names are
    accurate descriptions of SCANNING behaviour and are unchanged.
    [OpenSourceDiffVM-RevB.ino]
2026-02-21 Sync Java simulation with current firmware state
    - ScanState: rename IDLE → ONE_CHANNEL to match firmware
    - Constants: add CAL_BUILD_CYCLES, CAL_POINT_CYCLES, CAL_BUILD_WINDOW, AUTOZERO_CYCLES
    - AutoZero: use Constants.AUTOZERO_CYCLES instead of hardcoded 20
    - DacCalibrationTable: rename setCalPoint() → setPoint() to match firmware
    - DacCalibrationTableTest: update all setCalPoint() calls to setPoint()
    - DiffVMSimulator: replace loopIdle() with loopOneChannel() that mirrors
    firmware ONE_CHANNEL logic — per-channel stats array, channel-change
    detection (lastOneChannel sentinel), stats clear after each output,
    auto-zero interval check; rename scanCycleCount → cycleCount; update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
    [AutoZero.java, Constants.java, DiffVMSimulator.java]
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2026-03-06 Explicitly init CONFIG1 and CONFIG2 in initAndConfigure()
    Both registers were previously left at reset defaults, making the
    ADC configuration fragile against spurious resets. Now written
    explicitly with the same values, with comments documenting each
    field. Also adds readback and serial print for all four CONFIG
    registers for easier debug verification at startup.
    [OpenSourceDiffVM-RevB.ino]
2026-03-10 Add OPA828 buffer offset calibration constant
    Adds OPA828_OFFSET (default 0.0 V) to correct the HV divider buffer's
    DC offset, which is not cancelled by chopping since the OPA828 sits
    before the TMUX switches. The offset is subtracted from vxAtPreamp
    before the divider ratio scaling in computeInputVoltage(), HVDiv
    channel only.
    - cal set opa828 <v> — set offset in volts (e.g. 0.000016 for 16 uV)
    - cal factory — resets to 0.0
    - cal save/load — persisted in v2 cal_consts.bin (backward
    compatible: v1 files load with offset = 0.0)
    [OpenSourceDiffVM-RevB.ino]
2026-03-10 Add CAL-04a OPA828 buffer offset to calibration.md
    Documents why the offset is not cancelled by chopping, how it
    propagates through each divider ratio, the measurement procedure,
    and thermal drift considerations. Updates persistence table,
    calibration schedule, and firmware constants summary.
2026-03-15 Add precision filter design workflow and ADA4522-2 datasheet
    - filter-design.md: step-by-step workflow for building filters whose
    actual Q and -3dB frequency match design intent by measuring
    capacitors and back-calculating resistors with Okawa calculator
    - README.md: add Design Notes section linking to filter-design.md,
    Calibration.md, and ADC_analysis.md
    - ada4522-1_4522-2_4522-4.pdf, low-noise-inamp-nanovolt-sensitivity.pdf:
    add datasheets/references to repo
2026-03-15 Add --tol filter, 'help' alias, and component tolerance warning to resistor_finder.py
    - --tol T: filter results to within T% of target; prints "(no combinations
    within tolerance)" when nothing passes
    - 'help' accepted as alias for -h/--help
    - Warning printed when --tol < 0.5% (tighter than kit component tolerance)
    [resistor_finder.py]
2026-04-24 Add EWMA filtering, ADC refbuf, adcvref calibration, binary search RC settle, and misc fixes
    - AdjustedEWMA class: bias-corrected EWMA (equivalent N-point SMA) for per-channel
    measurements and auto-zero; shown alongside each reading; 'ewma <n>' command sets window
    - Auto-zero EWMA: successive auto-zero measurements fed through EWMA; filtered value
    applied as offset so zero drift tracks smoothly rather than jumping each cycle
    - Binary search RC filter settle: fixed per-step delay (RC_SETTLE_MS=80ms) so the
    analog RC filter between preamp and ADC settles before each sample; eliminates false
    convergence and wrong-sign readings from filter transients
    - railChanged flag in binary search: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
    [AD5760.h, OpenSourceDiffVM-RevB.ino]
2026-04-30 Rewrite signal-chain POST tests to use chop-demod with binary-searched null
    The signal_chain, polarity, and chop_symmetry POST tests were validating
    single-phase ADC reads against the input chain at gain x2000, which always
    rails on a healthy unit because the chain has a natural ~262 uV RTI residual
    offset (auto-zero compensates this in normal operation). Rewritten:
    - signal_chain runs binarySearchDAC() on GND input to find the per-unit null,
    caches it in s_postZeroDac, and validates the chopped demod is sane
    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
    [Teensy-pin-mapping-Diff-VM-revB.xlsx]
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2026-05-04 fix off-by-1 error in calc of allen variance
    [OpenSourceDiffVM-RevB.ino]
2026-05-08 Add Huber-clipped pooled-MAD outlier handling in demodulate()
    Replaces per-cycle hard rejection with Huber soft-clipping over a 256-deep
    pooled-MAD threshold; pool resets on any DAC code change or input mux switch
    so step transitions don't bias the next ~21 chop cycles toward the previous
    signal level. Runtime knob 'drj <k>' tunes clip threshold (k=10000 disables).
    Empirically eliminates the long-tau ADEV regression seen with hard rejection
    (rej-ON 1.4x worse at tau=960s) while preserving the short-tau noise win.
    Also fixes the postTestChopSymmetry 43% slope-asymmetry FAIL caused by pool
    contamination across 1-LSB DAC steps.
    [OpenSourceDiffVM-RevB.ino]
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2026-05-15 Add hardware-errata.md documenting board deltas vs Rev B schematics
    Captures the cap/resistor changes made on the assembled board that are
    not yet reflected in the KiCad files:
    - DAC Sallen-Key resistors reduced (9.01k/18k -> 1.68k/3.17k); filter is
    now underdamped, mitigated in firmware by chop-based search
    - AD8428 input RFI filter additions (33 nF differential + C15 = 1 uF Vcm)
    - ADS127L11 AAF cap C19 = 22 nF -> 47 nF (current ADEV baseline)
    - ADS127L11 VREFP 50 ohm series resistor added (decouples REFP_BUF
    dynamic current spikes from upstream reference network)
    - VrefRaw / J3 unbuffered output sags under preamp loading; needs an
    OPA828 buffer before MUX S3, postTestReferences bypa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
2026-05-15 Add IC-1 errata: U3 op-amp substitution OPA2140AID -> ADA4522-2
    Zero-drift chopper-stabilized dual op-amp on a JFET-input footprint;
    trades bandwidth and input bias current for ~300x lower offset and
    ~16x lower drift. Pin-compatible SOIC-8.
2026-05-15 BinSrch: distinguish DRDY timeout from rail; recover with AAF-scaled settle
    Two bugs in binarySearchDAC, both visible as "PhaseA rail=0" lines that
    caused the bisection to bracket through the linear window without ever
    finding an in-range read after large swings (e.g., Vx2 ±5 V → −3 V):
    1. acquireHalfCycle() sets overflow=true with overflowSample left at its
    default 0 when the ADC fails to produce DRDY in time. binarySearchDAC's
    "if (overflowSample > 0) low=mid+1 else high=mid-1" then misread the 0
    as "negative rail" and bisected the wrong direction. Now the lambda
    acquireWithRetry detects overflow=true + overflowSample=0 as a timeout
    and retries; only a real rail sample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
    [OpenSourceDiffVM-RevB.ino]
2026-05-15 BinSrch: backoff after 3 consecutive failures in chop-loop recovery
    Previously, if binarySearchDAC() failed (e.g., Vx outside the DAC's ±5 V
    range, or a hardware fault keeping the preamp pegged), runOneChopCycle
    would re-invoke it on every chop cycle — flooding the log and burning
    CPU on a recovery that physics can't deliver.
    Now both overflow-recovery sites in runOneChopCycle go through
    tryBinarySearchWithBackoff(), which caps consecutive failures at
    BS_FAIL_STREAK_LIMIT=3 and then suppresses further BinSrch calls
    until a chop cycle completes without overflow (which auto-resets the
    streak). One "limit reached" line is printed when suppression starts;
    subsequent overflows print one "supp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
    [OpenSourceDiffVM-RevB.ino]
2026-05-30 Add ohms measurement, RTS detector, manual R_ref refactor
    - OhmsMeas module: 4-wire-Kelvin ratiometric resistance against a
    manually-wired reference resistor. EMF cancellation via polarity
    reversal, auto-selected 1 V / 2.5 V excitation.
    - Remove R_ref mux control: pins 6/7/8 freed; selection moves from
    runtime cal slots to a const RREF_ALIASES[] table with `rref` CLI
    (r1..r8 or color names).
    - Add `ohms` bringup CLI (pol/exc direct control) for bench bisect.
    - RtsDetector module: TEMA-based step detector with persistence gate
    and dead-time for the per-chop-cycle Vx stream; opt-in via `rts on`.
    - OHMS-1 verification status logged: sub-ppm repeatability, ~20 ppm
    absolute against a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
    [OhmsMeas.cpp, OpenSourceDiffVM-RevB.ino]
2026-05-31 ohms: --repeat N, idle-low V_exc, cached AZ null
    - meas r gains --repeat N (alias -r) for batched measurements with
    Welford mean/sd/range summary; default still single-shot.
    - V_exc auto-idles to 1 V between measurements and at boot, so a wired
    R_ref dissipates ~6× less continuously (e.g., r4 + 500 Ω drops from
    ~300 µW to ~50 µW). meas r still escalates to 2.5 V when its R_ref
    needs it.
    - performAutoZero() caches the GND-null DAC code on first run and
    reuses it on subsequent AZ events, skipping the per-AZ
    binarySearchDAC() that was perturbing the DAC analog filter.
    Self-heals on overflow by invalidating the cache.
    - Measured impact on a 9.5 h ADEV baseline (autozero interva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
    [OhmsMeas.cpp, OpenSourceDiffVM-RevB.ino]
2026-06-02 ohms: --exc override, per-sense DAC cache, R_ref cal refinements
    Caching:
    - Add per-(sense, polarity) DAC-code cache in OhmsMeas. First measurement
    does a full BinSrch and caches the converged code; subsequent calls with
    the same R_ref + V_exc + sense + polarity skip BinSrch entirely. Cache
    invalidated on R_ref or V_exc change, or on overflow during a cached
    integration (self-healing).
    - New OhmsMeasApi callbacks setDacCode() / getCurrentDacCode() to plumb
    the cache through.
    CLI:
    - `meas r --exc 1|2.5` overrides the auto-selected V_exc rail. Useful
    when 2.5 V auto-select puts the BinSrch target near a saturation
    region the AAF can't recover from.
    BinSrch robustness:
    - Extend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
    [OhmsMeas.cpp, OpenSourceDiffVM-RevB.ino]
2026-06-08 ohms: hardware jig rev, 5450-anchored cal, new meas defaults
    Hardware jig revised 2026-06-05:
    - Removed r1 (20 Ω), r6 (1.9 MΩ), r7 (11 MΩ) — didn't work as intended
    at the extremes (r1: TMUX charge injection at 33 mA; r6/r7: BinSrch
    couldn't converge through AAF saturation at high source-Z, suspected
    AD8428 oscillation).
    - r5 replaced with new 50 kΩ blue resistor (was 200 kΩ blue).
    - r8 re-color-coded green (was yellow2). r1's "green" slot freed up
    because r1 was removed.
    - Practical coverage: ~50 Ω to ~500 kΩ at sub-ppm precision.
    R_ref re-calibration (full self-cal via Fluke 5450 + cross-checks):
    - 5450 had been self-cal'd a few years back against an in-cal
    Keithley 200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
    [OhmsMeas.cpp, OpenSourceDiffVM-RevB.ino]
2026-06-10 ohms: seeded BinSrch + linear-region AAF reset for high-R_ref cold starts
    Adds binarySearchDacSeeded (bracketed bisection with GND+null AAF park
    between railed probes), --nominal seeding for cold starts at r5 + high
    DUT, chop-cadence probe flushing, and hard-clip rail detection. Includes
    6/6 bench data and ADA4523-1 datasheet.
    [OhmsMeas.cpp, OpenSourceDiffVM-RevB.ino]
2026-06-14 config: show + persist demod rejection k (drj)
    drj k was runtime-only (file-scope global): invisible to config show
    and lost on reboot. Now shown in printStatus and the saved-config dump,
    stored in SavedConfig (EEPROM magic v3 0xD1FF0003 -- prior saved config
    invalidates once, re-save after flashing), restored on load with the
    same k >= 0.1 bound as the CLI, and reset to 8.0 by config factory.
    [OpenSourceDiffVM-RevB.ino]
2026-06-14 config: persist samples-per-half-cycle alongside drj (EEPROM v4)
    g_good_samples now saved/restored in SavedConfig. Restore assigns
    directly rather than via cmdSetSamples: that path rescales
    integrationCycles to hold wall-clock constant, but the saved pair is
    already consistent. Factory resets to 14. Magic bumped to 0xD1FF0004
    (one-time invalidation; re-save config after flashing).
    [OpenSourceDiffVM-RevB.ino]
2026-06-18 ohms: subtract auto-zero offset from each sense voltage
    DAC zero-code drift (ε₀) causes a differential error in the ratiometric
    R calculation proportional to (V_ref − V_dut)/(V_dut × V_ref) — about
    6 ppm per 8 µV of offset drift at the 1 kΩ / 2 kΩ R_ref operating point
    seen in bench data. The offset cancels in the R ratio only when it is
    removed from both sense voltages before the ratio is formed, not after.
    OhmsMeasApi gains getSignalChainOffset(), wired to scanner.autoZeroOffset
    (the GND-channel AZ measurement at the DAC null code). OhmsMeas.cpp
    subtracts it from each integrateAndCache result. With EMF cancellation a
    constant offset already cancels ratiometrically; the fix matt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
    [OhmsMeas.cpp, OpenSourceDiffVM-RevB.ino]
2026-06-18 ohms: interleave auto-zero at start and before every other run
    With the signal-chain offset now applied to each sense voltage, the offset
    needs to stay current during long repeat sequences. Auto-zero runs before
    rep 0, 2, 4, ... (i.e. at start of meas r, then after run 2, 4, ...) and
    prints the measured offset so drift is visible in the log.
    Each AZ adds ~200 ms (cached null code path) and is silent on success
    except for the compact "[zero: NNN.N nV]" line.
    [OhmsMeas.cpp, OpenSourceDiffVM-RevB.ino]
2026-06-18 az: restore sdev guard + 250 ms settle dwell
    Two features from the vx-buffer branch that are useful regardless of
    hardware: a 250 ms dwell before each AZ attempt (lets the input-mux
    Vx→GND switch transient decay through the ×2000 preamp/AAF before
    measuring) and a 250 nV two-rep sdev cap that rejects unsettled readings.
    On rejection the measurement retries once; if the second attempt also
    fails it warns and keeps the previous offset unchanged.
    [OpenSourceDiffVM-RevB.ino]
2026-06-20 ohms/ref: R_ref re-anchor, VrefRaw fix, AZ warning, --nominal help
    R_ref re-anchoring (RREF_ALIASES):
    - r2 black: 200.04825 → 200.04316 Ω (Hamon divider, R_true=200.00313080)
    - r3 yellow: 2002.07822 → 2002.02859 Ω (2nd-pass via 1062.0233 Ω cert)
    - r8 green: 5000.06199 → 5000.12373 Ω (2nd-pass via 1062.0233 Ω cert)
    VrefRaw circular correction fix: getRefCorrectionFactor() was applied to
    VrefRaw (J3 against itself = J²/TP1); now skipped for VrefRaw channel in
    both ONE_CHANNEL and SCANNING branches.
    REF_MEASURE_DAC_CODE 32764→32767; NOMINAL_REF_V updated to Keithley J3 value.
    POST: re-enable postTestReferences() (was bypassed with stale buffer comment).
    AZ: suppress intermedi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
    [OpenSourceDiffVM-RevB.ino]
2026-06-25 ohms: full R_ref re-anchor via K2002 + temp-corrected 5450 standards
    r2 black: 200.04316 → 200.13237 Ω (+446 ppm, 5450 190Ω)
    r3 yellow: 2002.02859 → 2002.03982 Ω (+56 ppm, K2002 SR1010 1K s-p)
    r4 white: 19999.9472 → 20000.07073 Ω (+6.2 ppm, avg 5450 10k/19k)
    r5 blue: 50010.4165 → 50009.54528 Ω (-17.4 ppm, avg 5450 19k/100k + SR1010 100k)
    r8 green: 5000.12373 → 5000.15707 Ω (+6.7 ppm, avg 5450 1k/1.9k/10k + SR1010 1k)
    All assigned values traceable to Keithley 2002 with temperature correction.
    Prior anchors had a systematic error; this supersedes all previous cal history.
    [OpenSourceDiffVM-RevB.ino]
2026-06-25 scan: allow GND channel in scan list
    Removes the restriction that blocked 'scan add GND'. GND is a valid
    diagnostic channel (preamp noise floor, zero-input baseline); the
    auto-zero uses ScopedInstrumentState so it does not conflict with a
    GND entry in the scan list.
    [OpenSourceDiffVM-RevB.ino]
